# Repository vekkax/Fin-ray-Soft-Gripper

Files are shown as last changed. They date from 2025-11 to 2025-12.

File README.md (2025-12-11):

# Fin-ray Soft Gripper for Object Manipulation with Multi-Robot Systems

This repository contains the open hardware and software files for the Fin-Ray soft gripper presented in:

> **S. Velasquez, A. Toro-Ossaba, J. C. Tejada, D. Sanin-Villa, and J. D. Núñez**,  
> *Fin-ray Soft Gripper for Object Manipulation with Multi-robot Systems*, MDPI Hardware, 2025.

The gripper is a 3D-printed Fin-Ray-effect end-effector with embedded piezoresistive sensing and an STM32-based controller that provides real-time force feedback for cooperative manipulation tasks in multi-robot systems.

---

## 1. Repository Contents

This repository provides all files required to reproduce the hardware and software described in the article:

| Item | Type | Description |
|---|---|---|
| `CAD/print_files/Geared_Arm_driver.stl`  | 3D file (.stl/.stp)  | Right geared arm (PLA), directly coupled to the servo output |
| `CAD/print_files/Geared_Arm_driven.stl`  | 3D file (.stl/.stp)  | Left geared arm (PLA), driven via 1:1 gear transmission |
| `CAD/print_files/Bracket.stl` | 3D file (.stl/.stp)  | Mounting bracket for the gripper (PLA) |
| `CAD/print_files/Gripper_Finger.stl` | 3D file (.stl/.stp)  | Fin-Ray soft finger (TPU) |
| `firmware/STM32_firmware` | STM32CubeIDE project | Firmware for the STM32-based controller |
| `software/plotter.py` | Python script | GUI for visualization and command/control (Figure 12 in the paper) |
| `media/Assembly.wmv` | Video | Instruction video for mechanical assembly |
| `README.md` | Markdown | This file: instructions, dependencies, and usage |

Naming and folder structure may vary slightly depending on your local setup, but all items listed in Table 10 of the paper are included in this repository.

---

## 2. Hardware Overview

The system consists of:

- **Two Fin-Ray-effect fingers** (TPU 95A, 3D printed)
- **HK15138 servomotor** (\~4.3 kg·cm at 6 V) to actuate both fingers via a 1:1 gear pair
- **Piezoresistive thin-film force sensor** (H52 Pressure Sensor, JESSINIE)
- **TB6612FNG motor driver breakout board**
- **STM32F407G-DISC1** development board for sensing, control, and communication
- Optional integration with the **Yahboom ROSMASTER X3** mobile robot platform

The gripper is designed for caging-based cooperative manipulation and is intended to handle approximately cubic objects in the range **20×20×20 cm to 30×30×30 cm**.

---

## 3. Design Files and 3D Printing

### 3.1 Fin-Ray Fingers

- **Files**:  
  - `CAD/print_files/Gripper_Finger.stl` (and optionally `.stp`)
- **Material**: TPU 95A  
- **Printer**: Ender 3 V2 (or similar FDM printer) 
- **Infill**: 100%  
- **Nozzle**: 0.4 mm  
- **Recommended configuration**:
  - Layer height: **0.20 mm**
  - Printing temperature: **220 °C**
  - Bed temperature: **30 °C**
  - Print speed: **20 mm/s**
  - Cooling: **disabled**
  - Retraction: **disabled**
  - Combing mode: **All**

> **Note:** A **direct-drive** extruder modification is strongly recommended for TPU to reduce jamming and improve retraction accuracy.

### 3.2 Rigid Parts (Bracket and Gears)

- **Files**:
  - `CAD/print_files/Bracket.stl`
  - `CAD/print_files/Geared_Arm_driver.stl`
  - `CAD/print_files/Geared_Arm_driven.stl`

- **Material**: PLA
- **Nominal gear parameters**:
  - 20 teeth
  - Module: 2.25 mm
  - Pressure angle: 20°
  - 1:1 transmission between driver and driven arm

Print these parts with standard PLA settings (e.g., 0.20 mm layer height, 30–40% infill) and verify dimensional accuracy of the gear mesh before assembly.

### 3.3 Asembly

Click the thumbnail below to watch the assembly video:

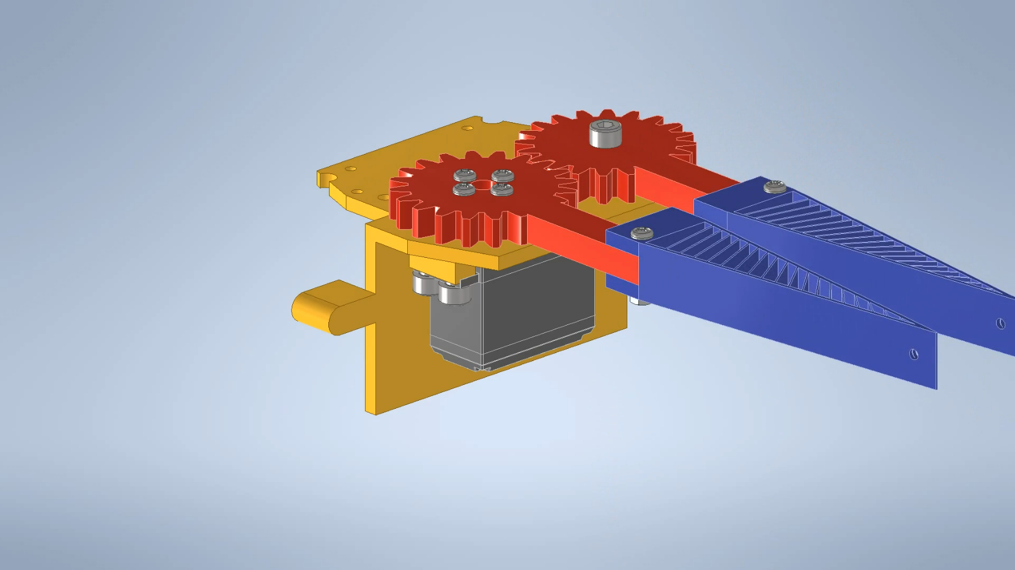
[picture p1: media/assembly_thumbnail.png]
Assembly Video

---

## 4. Bill of Materials (Summary)

A detailed bill of materials is provided in the paper (Table 6). The essential components are:

- HK15138 servomotor
- STM32F407G-DISC1 development board
- TB6612FNG dual H-bridge motor driver
- H52 piezoresistive force sensor (JESSINIE)
- Double-sided adhesive tape (e.g., Tesa 4965)
- 5 kΩ THT resistor (for voltage divider)
- MR105ZZ bearing
- Assorted M3 and M5 screws and hex nuts
- Optional: Yahboom ROSMASTER X3 platform and an external 6 V power supply for the servo

---

## 5. Firmware: STM32 Controller

### 5.1 Toolchain and Versions

The firmware has been developed and tested with:

- **STM32CubeIDE**: ≥ 1.15 (any recent 1.x version should be compatible)
- **Target MCU**: STM32F407 on the STM32F407G-DISC1 evaluation board
- **Language**: C (HAL-based, generated by STM32CubeMX inside CubeIDE)

### 5.2 Features

The embedded firmware implements:

- A **finite-state machine** with states: `START`, `CONTROL`, `IDLE`, `END`
- **ADC acquisition** of the force sensor via a voltage divider
- FIR-based low-pass filtering (moving-average, ~20 Hz cutoff)
- A **proportional controller** that adjusts servo pulse width based on force error
- Safety limits on PWM to respect servo mechanical range
- **USB serial** (virtual COM port) for:
  - Mode selection (`'s'`, `'i'`, `'c'`)
  - Telemetry streaming: force, setpoint, error, and pulse width

### 5.3 Building and Flashing

1. Open **STM32CubeIDE**.
2. Import the project from `firmware/STM32_FinRay_Gripper`.
3. Configure the correct **debug probe** (usually ST-Link) if needed.
4. Build the project (`Project → Build`).
5. Flash to the board (`Run → Debug` or `Run → Run`).

After flashing, the board will start in its initial state and will be ready to communicate via USB.

---

## 6. Python GUI (Plotter)

### 6.1 Environment and Dependencies

The graphical tool `software/plotter.py` was developed and tested with:

- **Python**: 3.10 or later (3.9+ recommended)
- **Dependencies**:
  - `pyqtgraph V0.13.7` 
  - `PyQt5 V2.15.11`
  - `pyserial V3.5`

Install them via:

```bash
pip install pyqtgraph pyqt5 pyserial

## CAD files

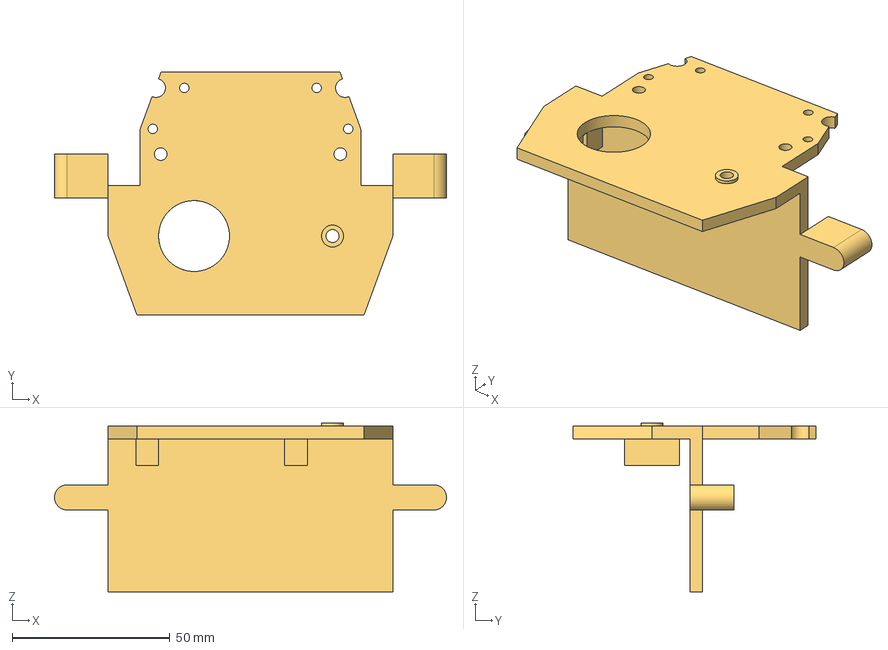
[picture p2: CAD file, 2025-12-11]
CAD/STEP_files/bracket.stp
124.4 x 77.0 x 53.6 mm

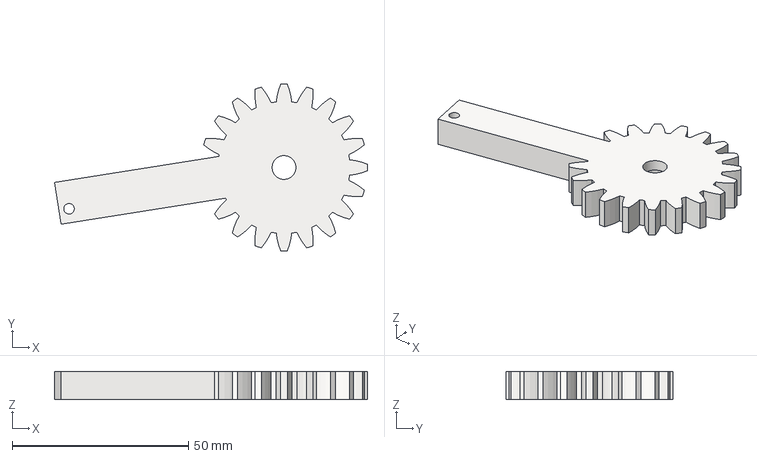
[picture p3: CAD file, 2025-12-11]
CAD/STEP_files/GearedArm_Driven.stp
88.8 x 47.4 x 8.00 mm

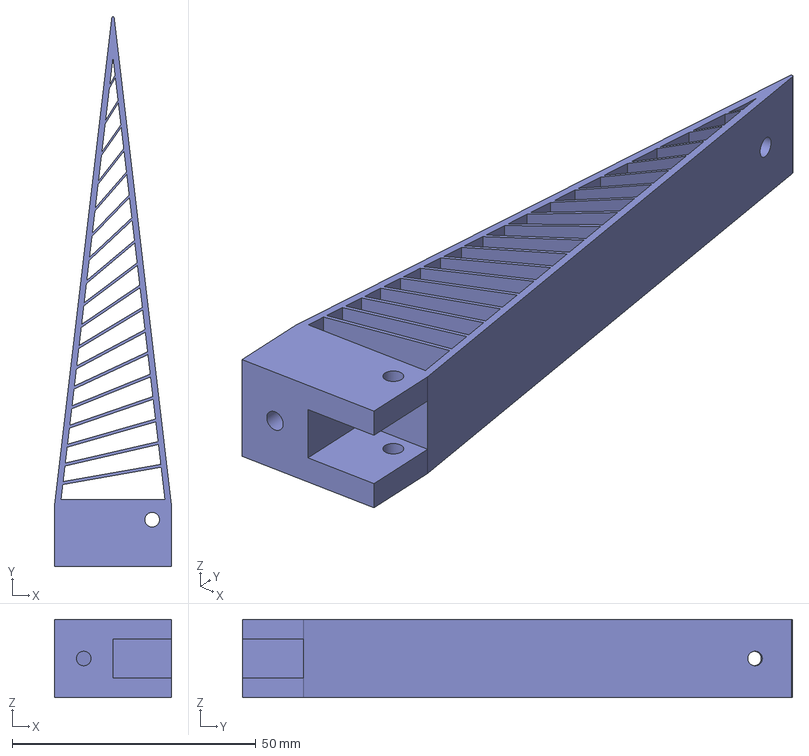
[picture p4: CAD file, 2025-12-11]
CAD/STEP_files/Gripper_Finger.stp
24.0 x 112.7 x 16.0 mm

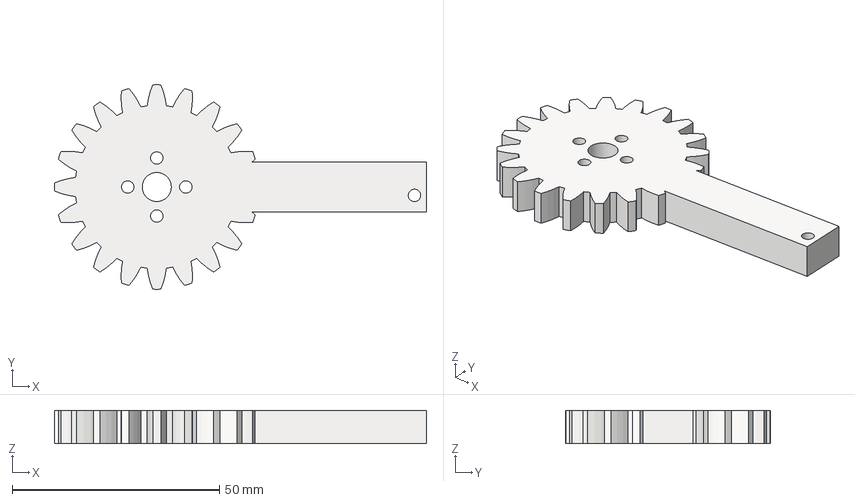
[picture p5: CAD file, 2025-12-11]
CAD/STEP_files/GearedArm_Driver.stp
89.6 x 49.3 x 8.00 mm

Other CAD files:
CAD/Print_files/Geared_Arm_Driven.stl
CAD/Print_files/Geared_Arm_Driver.stl
CAD/Print_files/Gripper_Finger.stl
CAD/Print_files/bracket.stl

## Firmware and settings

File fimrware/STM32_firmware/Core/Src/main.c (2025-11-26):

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
/* Includes ------------------------------------------------------------------*/
#include "main.h"
#include "usb_device.h"

/* USER CODE BEGIN Includes */
#include <stdio.h>
#include <string.h>
#include "usbd_cdc_if.h"
#include "gripper.h"
/* USER CODE END Includes */

/* USER CODE BEGIN PTD */
#define FIR_LENGHT 6


#define CCR_MAX 1250
#define CCR_MIN 250



/* USER CODE END PTD */

ADC_HandleTypeDef hadc1;

DAC_HandleTypeDef hdac;

I2C_HandleTypeDef hi2c1;

I2S_HandleTypeDef hi2s3;

TIM_HandleTypeDef htim2;
TIM_HandleTypeDef htim3;
TIM_HandleTypeDef htim4;

/* USER CODE BEGIN PV */
uint16_t pressure = 0;
float voltage =0;
float voltage_filt=0;
int Timer_val=0;
float peso;
volatile uint8_t usb_send_flag = 0;
char usb_msg_buffer[128];  // You can double-buffer if needed

//char msg[20];

// coefficients

float fir_coefficients[200];
float buffer_fir[200];
int16_t counter_fir;
float fir_out;
int index_fir;


// Gripper control
Gripper gripperState = CONTROL;
float setPoint = 0.0f;
float error = 0.0f;


char buffer[32];

/* USER CODE END PV */

void SystemClock_Config(void);
static void MX_GPIO_Init(void);
static void MX_I2C1_Init(void);
static void MX_I2S3_Init(void);
static void MX_ADC1_Init(void);
static void MX_DAC_Init(void);
static void MX_TIM2_Init(void);
static void MX_TIM3_Init(void);
static void MX_TIM4_Init(void);
/* USER CODE BEGIN 0 */
float filter( float x);

int limit_ccr(int lower_bound, int upper_bound, int ccr);
void gripperControl(float error);
void gripperHandler(Gripper gripperState, float error);
/* USER CODE END 0 */

/**
  * @brief  The application entry point.
  * @retval int
  */
int main(void)
{

  /* MCU Configuration--------------------------------------------------------*/

  /* Reset of all peripherals, Initializes the Flash interface and the Systick. */
  HAL_Init();

  /* Configure the system clock */
  SystemClock_Config();

  /* Initialize all configured peripherals */
  MX_GPIO_Init();
  MX_I2C1_Init();
  MX_I2S3_Init();
  MX_ADC1_Init();
  MX_DAC_Init();
  MX_TIM2_Init();
  MX_USB_DEVICE_Init();
  MX_TIM3_Init();
  MX_TIM4_Init();
  /* USER CODE BEGIN 2 */
  HAL_TIM_Base_Start_IT(&htim2);
  HAL_TIM_Base_Start_IT(&htim4);

  HAL_TIM_PWM_Start(&htim3, TIM_CHANNEL_1);	// start the pwm

  /* USER CODE END 2 */

  /* Infinite loop */
  /* USER CODE BEGIN WHILE */
  while (1)
  {
    /* USER CODE END WHILE */

    /* USER CODE BEGIN 3 */
    HAL_ADC_Start(&hadc1);
    HAL_ADC_PollForConversion(&hadc1, 0.25 );
    peso = (-2092.8 * voltage_filt * voltage_filt * voltage_filt + 18651 * voltage_filt * voltage_filt - 55684 * voltage_filt+ 55852);

    setPoint = 100.0f;
    error = setPoint - peso;


    Timer_val = __HAL_TIM_GET_COUNTER(&htim2);

    if (usb_send_flag) {
            if (CDC_Transmit_FS((uint8_t*)usb_msg_buffer, strlen(usb_msg_buffer)) == USBD_OK) {
                usb_send_flag = 0;
            }
            // Else: USBD_BUSY → retry on next loop
        }

  }
  /* USER CODE END 3 */
}

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
/* USER CODE BEGIN 4 */
float filter(float x) {
    // Shift previous samples
    float out;

	for(int i=0;i<200;i++){
		fir_coefficients[i]=1;
	}


    for(int i=0;i<199;i++){
    	buffer_fir[i]=buffer_fir[i+1];
    }

    buffer_fir[199]=x;
    out=0;

    for(int i = 0;i<200;i++){
    	out += (float)buffer_fir[i]/200;
    }

    return out;
}

void HAL_TIM_PeriodElapsedCallback(TIM_HandleTypeDef *htim){
	if (htim == &htim2){
		HAL_GPIO_TogglePin(LD4_GPIO_Port, LD4_Pin);
		pressure = HAL_ADC_GetValue(&hadc1);
		voltage=((float)pressure)* 3.3f /4095.0f;

		//Filter
		fir_out=filter(pressure);
		voltage_filt=((float)fir_out)*3.3f/4095.0f;


	}

	if (htim == &htim4){

		// every
		HAL_GPIO_TogglePin(LD5_GPIO_Port, LD5_Pin);
		gripperHandler(gripperState, error);

		if (!usb_send_flag) {
			snprintf(usb_msg_buffer, sizeof(usb_msg_buffer),
					 "fuerza sensada: %08.4f, set point: %08.4f, error: %08.4f, accion: %04lu\r\n"/*, voltage raw: %08.4f, voltage filtered: %08.4f"*/,
					 peso, setPoint, error, TIM3->CCR1/*, voltage,voltage_filt*/);

			usb_send_flag = 1;
		}


	}

}


int limit_ccr(int lower_bound, int upper_bound, int ccr){
	if(ccr > upper_bound){
		return upper_bound;
	}
	else if (ccr < lower_bound){
		return lower_bound;
	}
	else{
		return ccr;
	}
}

void gripperControl(float error){
	float curr_CCR = (float)(htim3.Instance->CCR1);
	float kp = 0.1f;

	curr_CCR += kp*error;

	htim3.Instance->CCR1=limit_ccr(CCR_MIN, CCR_MAX,(int)curr_CCR);

}

void gripperHandler(Gripper gripperState, float error){
	switch (gripperState) {
	    	case START:
	    		htim3.Instance->CCR1 = CCR_MIN;  // 1.12 ms pulse : start position
	    		break;

	    	case CONTROL:
	    		gripperControl(error);  // 1.72 ms pulse : mid-range control
	    		break;

	    	case END:
	    		htim3.Instance->CCR1 = 750-1;  // 1.92 ms pulse : end position
	    		break;

	    	case IDLE:							// sets the servo motor to idle, no control
	    		htim3.Instance->CCR1 = 0;
	    		break;
	}
}




/* USER CODE END 4 */
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


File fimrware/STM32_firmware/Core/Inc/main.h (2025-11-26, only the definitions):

#define CS_I2C_SPI_Pin GPIO_PIN_3
#define CS_I2C_SPI_GPIO_Port GPIOE
#define PC14_OSC32_IN_Pin GPIO_PIN_14
#define PC14_OSC32_IN_GPIO_Port GPIOC
#define PC15_OSC32_OUT_Pin GPIO_PIN_15
#define PC15_OSC32_OUT_GPIO_Port GPIOC
#define PH0_OSC_IN_Pin GPIO_PIN_0
#define PH0_OSC_IN_GPIO_Port GPIOH
#define PH1_OSC_OUT_Pin GPIO_PIN_1
#define PH1_OSC_OUT_GPIO_Port GPIOH
#define OTG_FS_PowerSwitchOn_Pin GPIO_PIN_0
#define OTG_FS_PowerSwitchOn_GPIO_Port GPIOC
#define PDM_OUT_Pin GPIO_PIN_3
#define PDM_OUT_GPIO_Port GPIOC
#define B1_Pin GPIO_PIN_0
#define B1_GPIO_Port GPIOA
#define Pressure_sensor_Pin GPIO_PIN_1
#define Pressure_sensor_GPIO_Port GPIOA
#define I2S3_WS_Pin GPIO_PIN_4
#define I2S3_WS_GPIO_Port GPIOA
#define Filter_out_Pin GPIO_PIN_5
#define Filter_out_GPIO_Port GPIOA
#define Servo_Pin GPIO_PIN_6
#define Servo_GPIO_Port GPIOA
#define SPI1_MOSI_Pin GPIO_PIN_7
#define SPI1_MOSI_GPIO_Port GPIOA
#define BOOT1_Pin GPIO_PIN_2
#define BOOT1_GPIO_Port GPIOB
#define CLK_IN_Pin GPIO_PIN_10
#define CLK_IN_GPIO_Port GPIOB
#define LD4_Pin GPIO_PIN_12
#define LD4_GPIO_Port GPIOD
#define LD3_Pin GPIO_PIN_13
#define LD3_GPIO_Port GPIOD
#define LD5_Pin GPIO_PIN_14
#define LD5_GPIO_Port GPIOD
#define LD6_Pin GPIO_PIN_15
#define LD6_GPIO_Port GPIOD
#define I2S3_MCK_Pin GPIO_PIN_7
#define I2S3_MCK_GPIO_Port GPIOC
#define VBUS_FS_Pin GPIO_PIN_9
#define VBUS_FS_GPIO_Port GPIOA
#define OTG_FS_ID_Pin GPIO_PIN_10
#define OTG_FS_ID_GPIO_Port GPIOA
#define OTG_FS_DM_Pin GPIO_PIN_11
#define OTG_FS_DM_GPIO_Port GPIOA
#define OTG_FS_DP_Pin GPIO_PIN_12
#define OTG_FS_DP_GPIO_Port GPIOA
#define SWDIO_Pin GPIO_PIN_13
#define SWDIO_GPIO_Port GPIOA
#define SWCLK_Pin GPIO_PIN_14
#define SWCLK_GPIO_Port GPIOA
#define I2S3_SCK_Pin GPIO_PIN_10
#define I2S3_SCK_GPIO_Port GPIOC
#define I2S3_SD_Pin GPIO_PIN_12
#define I2S3_SD_GPIO_Port GPIOC
#define Audio_RST_Pin GPIO_PIN_4
#define Audio_RST_GPIO_Port GPIOD
#define OTG_FS_OverCurrent_Pin GPIO_PIN_5
#define OTG_FS_OverCurrent_GPIO_Port GPIOD
#define SWO_Pin GPIO_PIN_3
#define SWO_GPIO_Port GPIOB
#define Audio_SCL_Pin GPIO_PIN_6
#define Audio_SCL_GPIO_Port GPIOB
#define Audio_SDA_Pin GPIO_PIN_9
#define Audio_SDA_GPIO_Port GPIOB
#define MEMS_INT2_Pin GPIO_PIN_1
#define MEMS_INT2_GPIO_Port GPIOE

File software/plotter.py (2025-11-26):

import pyqtgraph as pg
from pyqtgraph.Qt import QtGui, QtCore
from PyQt5.QtWidgets import QApplication, QWidget, QPushButton, QVBoxLayout, QHBoxLayout, QLabel

import serial
import sys
import re
from collections import deque
import time
import random
import csv
import atexit
import signal

# === CONFIGURATION ===
PORT = 'COM7'  # ← change this to match your COM port
BAUD = 115200
MAX_POINTS = 500
UPDATE_INTERVAL_MS = 50  # Update plot every 50ms (~20Hz)

# === REGEX PARSER ===
pattern = re.compile(
    r"fuerza sensada:\s*([-+]?[0-9.]+), set point:\s*([-+]?[0-9.]+), error:\s*([-+]?[0-9.]+), accion:\s*([0-9]+)"
)

# === DATA BUFFERS ===
peso = deque([0.0]*MAX_POINTS, maxlen=MAX_POINTS)
setpoint = deque([0.0]*MAX_POINTS, maxlen=MAX_POINTS)
error = deque([0.0]*MAX_POINTS, maxlen=MAX_POINTS)
accion = deque([0]*MAX_POINTS, maxlen=MAX_POINTS)

# === SERIAL SETUP ===
try:
    ser = serial.Serial(PORT, BAUD, timeout=0.01)
except Exception as e:
    print(f"[WARN] Could not open serial {PORT}: {e}")
    ser = None

def send_serial(cmd: bytes):
    """Send a single-byte command to the serial port (safe wrapper)."""
    try:
        if ser is not None and getattr(ser, "is_open", False):
            ser.write(cmd)
            print(f"[USB OUT] {cmd!r}")
        else:
            print("[WARN] Serial port not open")
    except Exception as e:
        print(f"[ERROR] Failed to write to serial: {e}")

# === PYQTGRAPH SETUP ===
app = QApplication([])
win = pg.GraphicsLayoutWidget(title="Real-Time Gripper Visualization")
win.setMinimumSize(800, 600)

# Plot 1: Peso & Set Point
p1 = win.addPlot(title="Force vs Set Point")
curve_peso = p1.plot(pen='b', name="Force")
curve_setp = p1.plot(pen='y', name="Set Point")
p1.enableAutoRange('y', True)

# Plot 2: Error
win.nextRow()
p2 = win.addPlot(title="Error")
curve_error = p2.plot(pen='r')
p2.enableAutoRange('y', True)

# Plot 3: Acción
win.nextRow()
p3 = win.addPlot(title="Control Action")
curve_accion = p3.plot(pen='g')
p3.enableAutoRange('y', True)

# --- Control panel (buttons that send 's', 'i', 'c') ---
control_panel = QWidget()
cp_layout = QVBoxLayout()
control_panel.setLayout(cp_layout)

lbl = QLabel(f"Serial: {PORT} @ {BAUD}")
cp_layout.addWidget(lbl)

btn_start = QPushButton("Start")
btn_idle = QPushButton("Idle")
btn_control = QPushButton("Control")

# connect buttons to send_serial with the requested characters
btn_start.clicked.connect(lambda: send_serial(b's'))
btn_idle.clicked.connect(lambda: send_serial(b'i'))
btn_control.clicked.connect(lambda: send_serial(b'c'))

cp_layout.addWidget(btn_start)
cp_layout.addWidget(btn_idle)
cp_layout.addWidget(btn_control)
cp_layout.addStretch()

# Put the plot widget and the control panel side by side in a main widget
main_widget = QWidget()
main_layout = QHBoxLayout()
main_widget.setLayout(main_layout)
main_layout.addWidget(win, stretch=3)
main_layout.addWidget(control_panel, stretch=1)

main_widget.resize(1000, 600)
main_widget.show()

# === UPDATE FUNCTION ===
def update():
    global peso, setpoint, error, accion

    while ser.in_waiting:
        try:
            line = ser.readline().decode(errors='ignore').strip()
            if line:
                print(f"[USB] {line}")

            match = pattern.search(line)
            if match:
                peso.append(float(match.group(1)))
                setpoint.append(float(match.group(2)))
                error.append(float(match.group(3)))
                accion.append(int(match.group(4)))
        except Exception as e:
            print(f"[ERROR] {e}")
            pass

    # Redraw plots every frame, even if values haven't changed
    x = list(range(MAX_POINTS))

    curve_peso.setData(x, list(peso), copy=True)
    curve_peso.setPos(0, random.uniform(0, 1e-10))

    curve_setp.setData(x, list(setpoint), copy=True)
    curve_setp.setPos(0, random.uniform(0, 1e-10))

    curve_error.setData(x, list(error), copy=True)
    curve_error.setPos(0, random.uniform(0, 1e-10))

    curve_accion.setData(x, list(accion), copy=True)
    curve_accion.setPos(0, random.uniform(0, 1e-10))

    # Force event processing
    pg.QtGui.QApplication.processEvents()

def save_plot_data():
    try:
        with open('plot_data.csv', 'w', newline='') as f:
            writer = csv.writer(f)
            # Write headers
            writer.writerow(['Index', 'Force', 'Setpoint', 'Error', 'Action'])
            # Write data
            for i in range(len(peso)):
                writer.writerow([
                    i,
                    peso[i],
                    setpoint[i],
                    error[i],
                    accion[i]
                ])
        print("[INFO] Data saved to plot_data.csv")
    except Exception as e:
        print(f"[ERROR] Failed to save data: {e}")
    finally:
        # Attempt to close serial port cleanly
        try:
            if ser is not None and getattr(ser, "is_open", False):
                ser.close()
                print("[INFO] Serial port closed")
        except Exception as e:
            print(f"[WARN] Failed to close serial: {e}")

# Register the cleanup function
atexit.register(save_plot_data)

# Make sure Qt quit triggers the same save routine
try:
    app.aboutToQuit.connect(save_plot_data)
except Exception:
    pass

# Allow Ctrl-C in the terminal to quit the app
def _handle_sigint(sig, frame):
    print("[INFO] SIGINT received, exiting...")
    # This will cause the Qt event loop to quit and trigger aboutToQuit/atexit
    QApplication.quit()

signal.signal(signal.SIGINT, _handle_sigint)

# === START TIMER ===
timer = QtCore.QTimer()
timer.timeout.connect(update)
timer.start(UPDATE_INTERVAL_MS)

# === RUN APP ===
if __name__ == '__main__':
    print(f"[INFO] Plotting live from {PORT}...")
    if (sys.flags.interactive != 1) or not hasattr(QtCore, 'PYQT_VERSION'):
        QApplication.instance().exec_()

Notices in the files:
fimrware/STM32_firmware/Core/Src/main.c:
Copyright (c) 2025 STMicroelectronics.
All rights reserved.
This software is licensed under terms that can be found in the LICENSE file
